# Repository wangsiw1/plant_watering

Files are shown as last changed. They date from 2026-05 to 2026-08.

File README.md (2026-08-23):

# Plant watering

A simple 1 main to multiple workers hardware setup to monitor soil moisture and water series of plant pots automatically.

Main device:
- Gateway of the setup, managing the workers, hosting web server for user interactions
- Monitoring water level from water container with capacitive sensor
- Controlling pump for watering

Worker device:
- Monitoring 1 or more soil moisture sensors and reporting to main
- Controlling 1 or more two-position three-way solenoid valves to redirect water to different plant pots

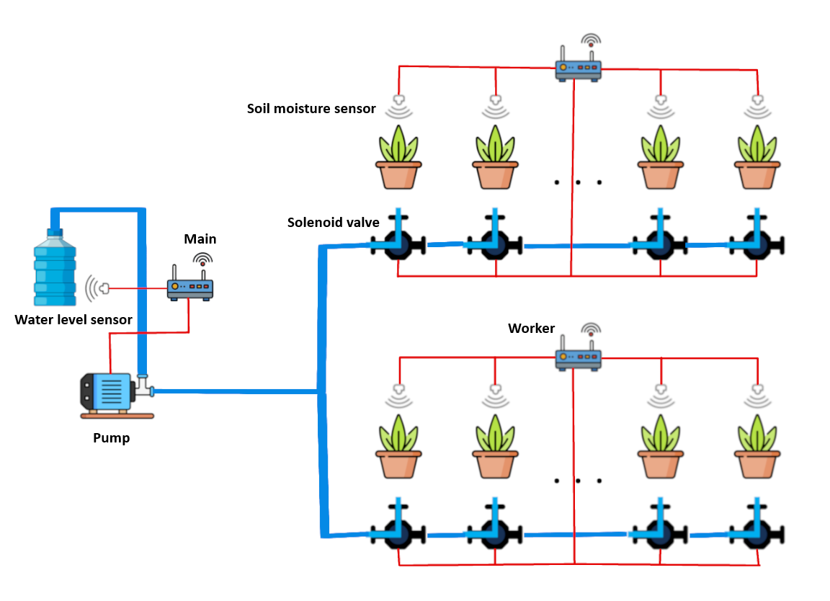
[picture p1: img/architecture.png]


> **Disclaimer**: LLM has been used in this project as part of the learning process. On hardware side, Google Gemini, Claude AI, and OpenAI ChatGPT were used to explain usage of components, knowledge cross check, and parts recommendation. On software side, GitHub Copilot agent in Visual Studio Code was used to generate part of the code based on design document. Human review, revise, and test was conducted every round of generation.

## Design

- MCU:
    Considering the price and wireless requirement, ESP32 C3 was chosen.

- Power: 
    - Since main device will do the heavy duties(Always on, WiFi connection and web server host, pump driving, etc.), a 12V DC input using common DC barrel plug adapter was used to provide continuous power. 
    - Amount of workers can be scaled up and locations varies based on the plant location, while worker can be less power hungry, rechargeable LiPo battery is used.

- Communication:
    - Bluetooth between main and worker for sensor reading reporting and watering command sending. 
    - For easy scalability and setup process, all devices use BLE broadcast to send messages and filter message by MAC address of sendor, no connection is required.

- Function:
    - Users add workers to main by Bluetooth MAC address. Main will probe added workers and learn details upon first status report(worker having 1/8/16 ports available)
    - Users set watering duration, soil moisture threshold, and automatic watering interval for each plant pot, plus the system-wide active time range and data-sync interval.
    - After enabling auto watering, main collects sensor readings, starts pump and commands workers to trigger solenoid valve, then let workers go to deep sleep mode during time interval to save power.
    - Solenoid valve will be triggered one by one, meaning only one pot will be watered at a single time, due to battery current and pump power limitation.

## Hardware

### V1

For the initial idea, because of the nature of similarity between main and worker(1 sensor, 1 peripheral), it was decided to use a single PCB design for both devices with compatibility added to fit different parts on the same board. 

Since a 12V pump was used, a 12V solenoid valve was also chosen. Then all differences are as follow:
- Different sockets for pump(screw terminal) and valve(GH 1.25 socket), lined up next to each other on the PCB, use one of them as needed.
- Different sensor pin numbers(3 pins for soil moisture and 4 pins for water level), since both are XH 2.54, and both have pin 3 as data output, put a single 4 pin footprint, and use different parts.
- Different VIN and GND pin sequences for sensors, use two 0 ohm with solder pads in 2*2 grid to bridge trace to achieve different sequences on different orientations.

Being first version of the project and first personal hardware project, this one has severe design flaws due to lacking of knowledge, hardware understanding, and product reasearch. It was scrapped later.

#### Shared Schematic & PCB

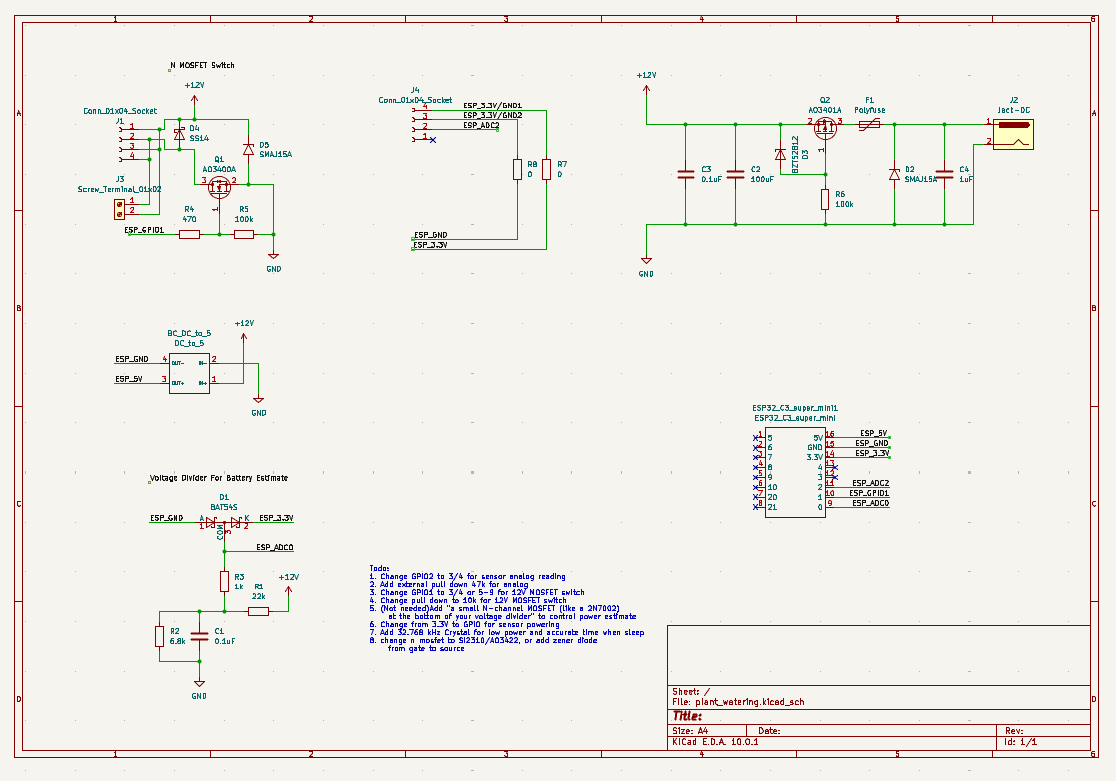
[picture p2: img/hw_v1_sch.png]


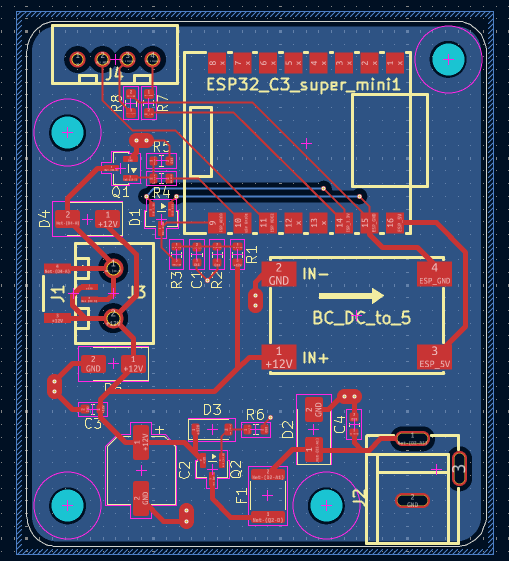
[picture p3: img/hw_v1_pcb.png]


#### Main

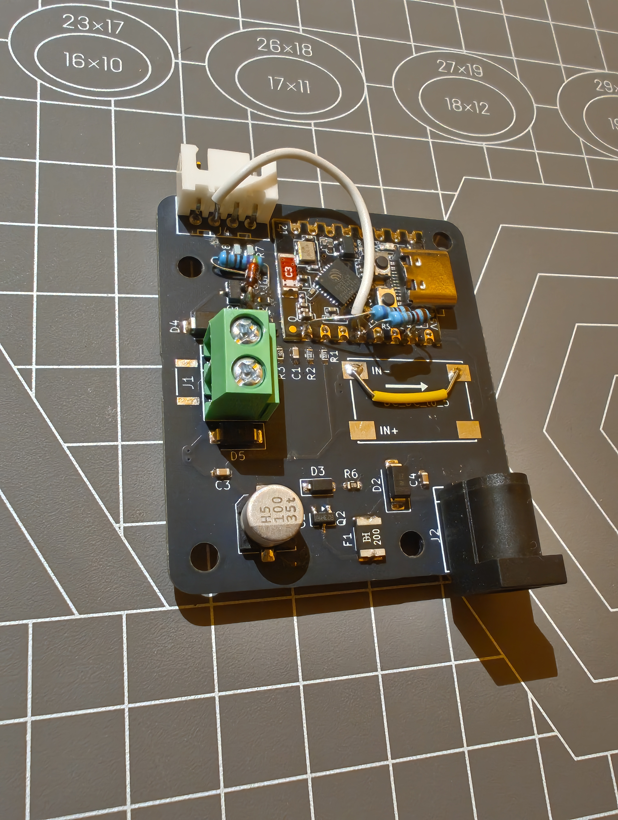
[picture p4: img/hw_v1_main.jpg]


#### Worker

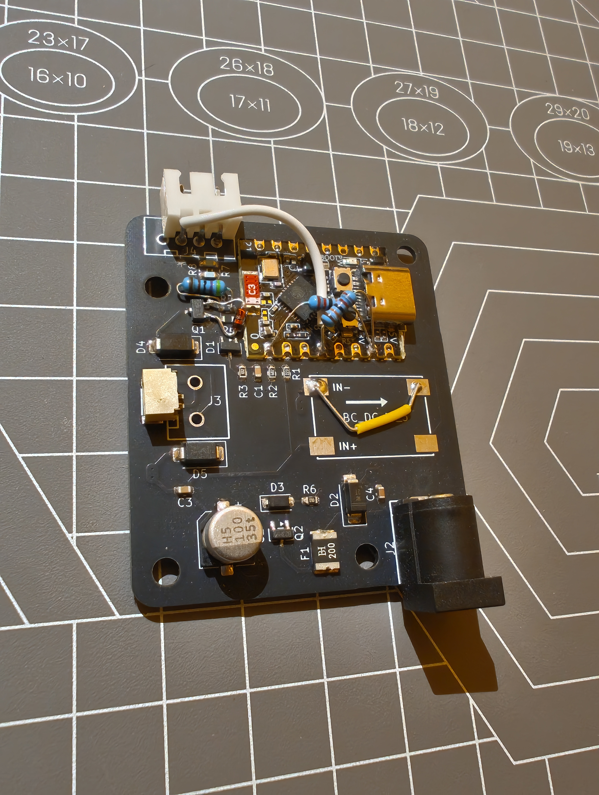
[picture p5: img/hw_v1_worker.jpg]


### V2

Design of main device is basically V1, but with dimension changed to fit case and worker compatibility removed, as worker is fully redesigned.

For worker, after reviewing the total cost of V1 worker, it was really expensive for users owning dozens of pots of plant. In V2, worker had numbers of monitored plant expand from 1 to 8, and can be expanded to 16 in the future.

To reduce cost and weight, power was cut from 12V to 5V. Battery was moved from large lithium battery pack to flat LiPo with charging & 5V boost converter module. Solenoid valve was also changed to a different 5V version.

There are still several minor issues with this version, not function breaking, but are documented in the schematic and shall be fixed in the next revision.

#### Main

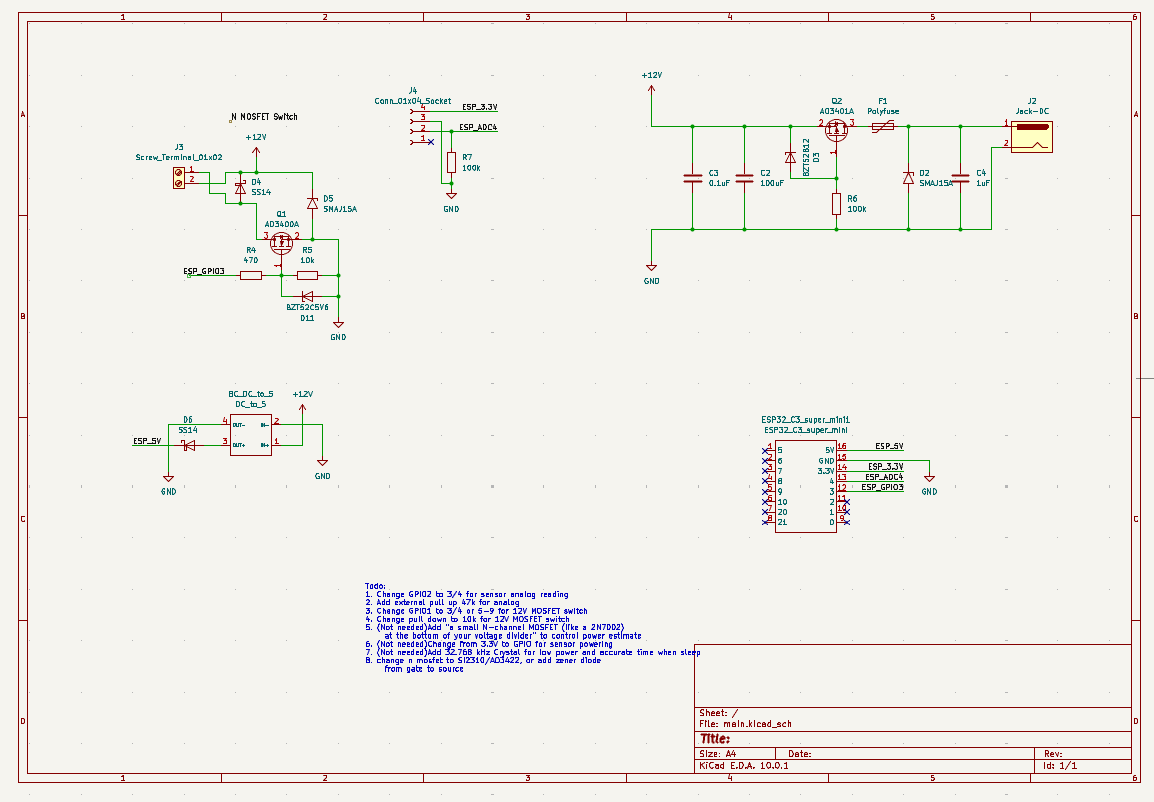
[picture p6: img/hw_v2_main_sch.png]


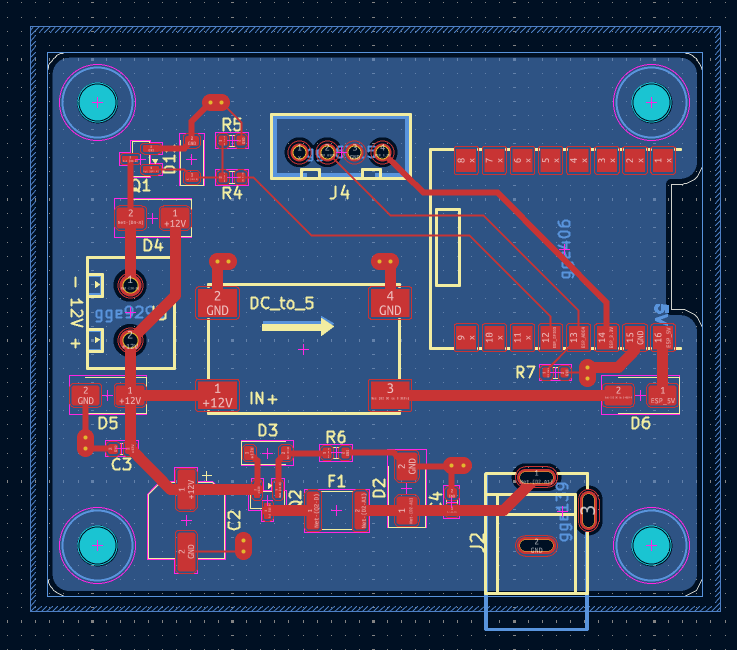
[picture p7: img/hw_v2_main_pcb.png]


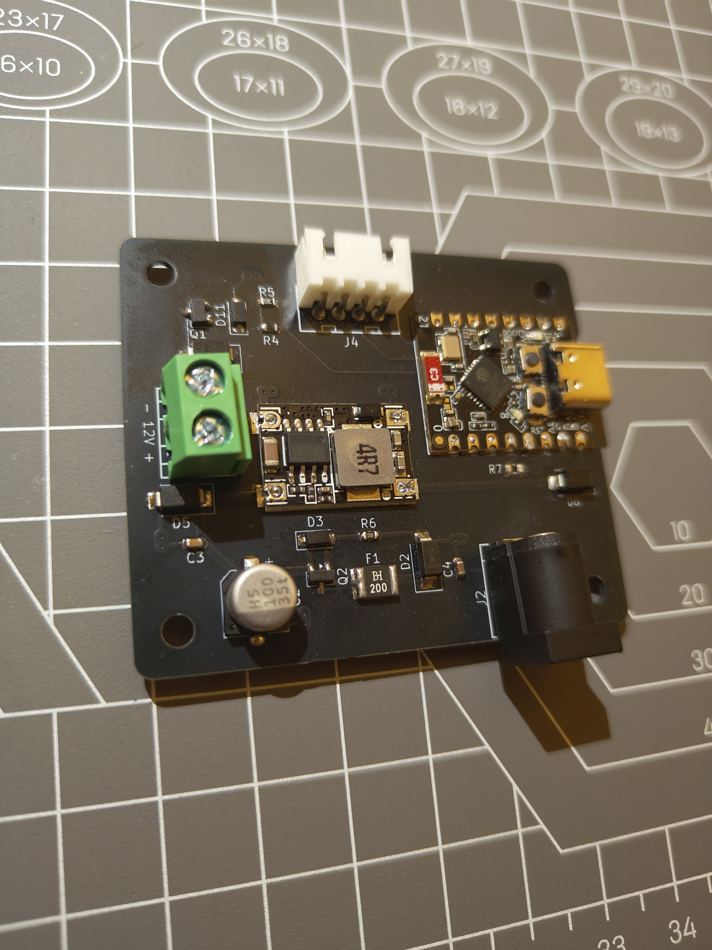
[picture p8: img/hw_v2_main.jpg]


#### Worker

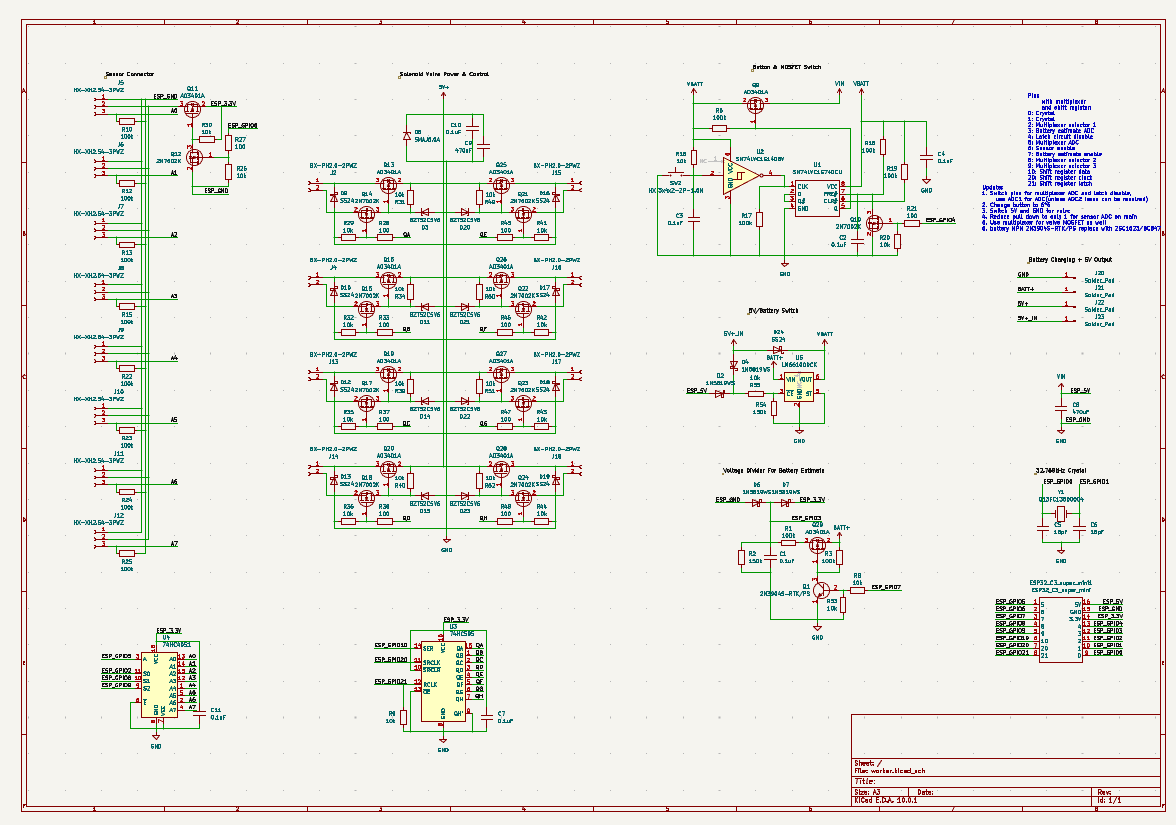
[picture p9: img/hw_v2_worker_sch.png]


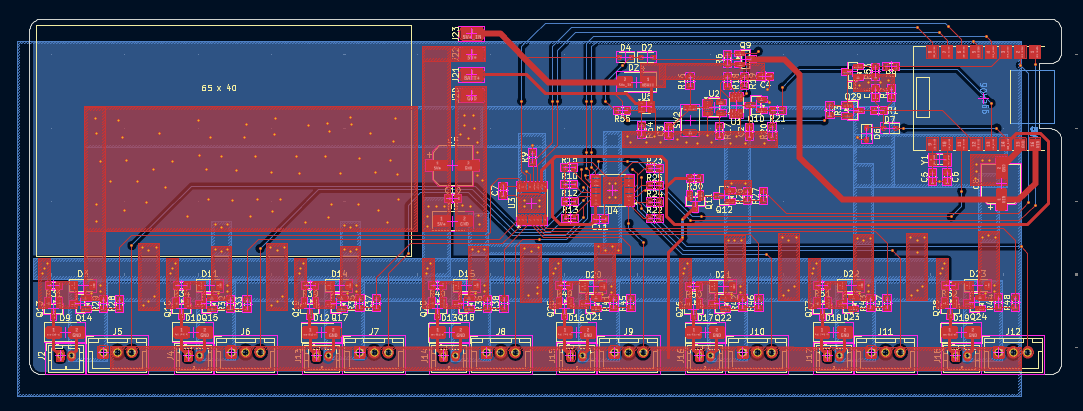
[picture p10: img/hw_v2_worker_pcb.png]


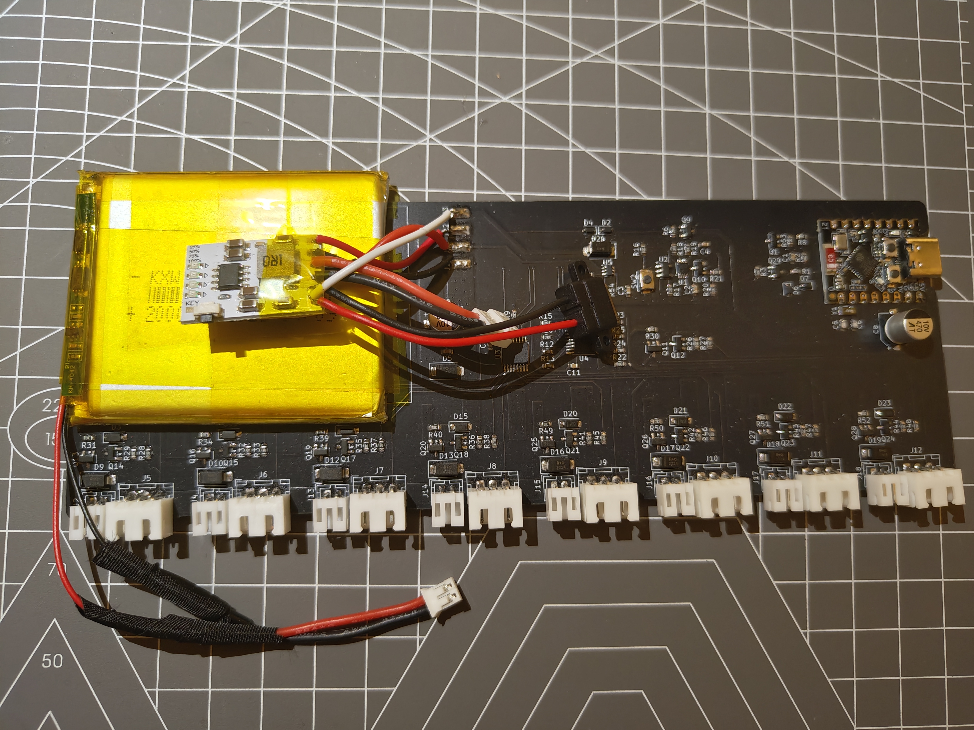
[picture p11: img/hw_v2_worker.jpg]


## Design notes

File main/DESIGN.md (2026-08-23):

# ESP32-C3 pot plan watering system — Design & Notes

This document collects requirements, design decisions, implementation notes of software for the main device of ESP32-C3 pot plant watering project.

Note: Hardware specifications other than ESP32 C3 is not in the scope.

## Overview

Goal: As a main device, it will have a non contact capacitive water level sensor and a water pump connnected. The device will collect soil sensor data from worker devices through Bluetooth broadcast, then based on the settings and sensor data, it will send commands to worker devices and start pump. This main device will also host an HTTP server that serves a web page for users to get info and config system. Detailed components are following:

- WiFi (WiFiProvisioner)
- mDNS
- OTA (ArduinoOTA, Async?)
- Wireless data reading and command sending (Bluetooth broadcast? No wifi channel issue, but range? packet loss?)
- HTTP server with a small web UI for worker device add/remove, settings, info, etc.
- Settings persistence across reboots
- Manual actions via the UI

## Functionalities

- Setup mDNS for easier web page access
- With WiFiProvisioner, let users connect to the on board WiFi first to select WiFi router to connect to. So that users can access web page directly through exsiting router without needing to change WiFi all the time.
- Bluetooth keeps listening the broadcast data and broadcasts commands when required. 
- ArduinoOTA for OTA. (Firmware image integrity check and rollback on fail need to be checked)
- Web page:
  - Show digital data from sensor
  - Last pump activation time
  - Set water pump activation time during the day
  - Cooldown after previous watering, no watering during this period, wait for water to go into soil
  - Manual pump activation
  - Enable/disable audo watering function based on schedule and soild moisture
  - Apply and save all inputs
  - Add worker node using Bluetooth MAC address
  - List of added worker nodes grouped by worker device, each worker shows:
    - Battery level, last sync time, and RSSI
    - Worker name input
    - For each pot on that worker: soil moisture, last watering time, threshold, watering duration, pot name, and manual watering button

### Details

- mDNS
  - Default settings
  - Domain name: plant-watering-\<WIFI_MAC_LAST_6_HEX\>.local
  - Initialize once and follow WiFi/IP events across reconnects; retry only if
    initial mDNS setup failed

- WiFiProvisioner
  - Default settings
  - On an eligible crash recovery with saved credentials, a connection timeout
    skips blocking provisioning so automation can boot offline and WiFi can
    reconnect in the background
  - All other failed startup connections retain the blocking provisioning flow

- ArduinoOTA
  - Main and worker OTA uploads and worker deployment require auto mode to be
    turned off first
  - Reject enabling auto mode while an OTA operation is active
  - Main and worker builds define a nonzero `FW_MIN_ALLOWED_VERSION` no greater
    than their own `FW_VERSION`
  - Reject packages below that role-specific minimum and reject reinstalling
    the currently running version; allow upgrades and rollbacks down to the floor

- Auto mode recovery
  - Keep the armed intent in validated RTC no-init memory, not NVS
  - Resume only after panic, interrupt-watchdog, task-watchdog, or other
    watchdog resets and only after normal startup initialization completes
  - Power-on, brownout, external, software/OTA, deep-sleep, SDIO, and unknown
    reset reasons always start in manual mode

- Web UI (Minimum style while easy to view)
  - Each input below has a tooltip explain the usage 
  - Title/header ("Plant Watering (\<name\>)", name is \<WIFI_MAC_LAST_6_HEX\> by default)
  - Name input (255 char max, empty by default. If non-empty, replace name in title)
  - Current time (hour:minute), and input to set manually
  - Water tank info from sensor: High/Low
  - Time range input of watering activation: 24-hour start and end
  - Interval of data sync input (seconds with hardcoded min/max)
  - Button to manually activate pump
  - Button to apply all changes
  - Major button to start auto watering
  - ID (12 hex digits of Bluetooth MAC address, upper or lower cases) input and add button to add worker node to list
  - Major button to apply changes to inputs
  - List of added worker nodes grouped by worker device:
    - Worker header shows MAC address, battery percentage, last sync time, and RSSI
    - Worker name input
    - Remove button removes the whole worker device from the list
    - Each pot row shows soil moisture data, persistent last automatic watering time, threshold, watering duration, watering interval, and a manual watering button
    - Pot name and worker name are stored in fixed 65-byte buffers, so the web UI clamps names to 64 UTF-8 bytes total, which is about 64 ASCII characters or about 16 4-byte emoji/CJK characters
  - Callapsed log list and system health info

- Hardware
  - Main firmware supports multiple hardware targets selected at build time
  - Main-device status LED
    - GPIO 8, active-low, onboard single-color blue LED
    - Driven by LEDC channel 0 at 5 kHz with 8-bit PWM resolution
    - The status controller updates every 20 ms in an independent low-priority
      FreeRTOS task, including while WiFi provisioning blocks the main setup
      flow
    - Display priority is logical and independent of FreeRTOS task priority:
      OTA update, low water tank, WiFi, watering, worker synchronization, then
      normal/idle
    - Main or worker OTA: 100 ms on and 100 ms off continuously (5 flashes per
      second)
    - Low tank (at or below 2800 mV): 500 ms on and 500 ms off continuously
      (1 flashes per second)
    - WiFi provisioning, initial connection, or reconnection: cosine-eased
      breathing over 2 seconds, from 10% PWM brightness at 0 ms to 70% at
      1000 ms and back to 10% at 2000 ms
    - WiFi connected: one 250 ms full-brightness confirmation flash, then off
      or the next applicable lower-priority state
    - Watering or manual pump active: three 100 ms flashes separated by 100 ms off,
      followed by 1500 ms off; repeat every 2 seconds
    - Worker synchronization: two 100 ms flashes separated by 100 ms off,
      followed by 1700 ms off; repeat every 2 seconds
    - Normal/idle: off
    - Pattern intervals are half-open and a newly selected highest-priority
      pattern restarts at its first phase
  - `HW_TARGET_V1_REV_A`
    - Pump activation pin: GPIO 1
    - Water tank level sensor reading pin: GPIO 3
  - `HW_TARGET_V2_REV_A`
    - Pump activation pin: GPIO 3
    - Water tank level sensor reading pin: GPIO 4

- Logics
  - Time
    - 24-Hour, minute level (HH:mm)
    - Input by user via web UI
    - Local-first operation: NTP is optional and manual HH:mm input must work on a network without Internet access
    - Keep a hidden epoch day so multi-day watering intervals can be measured while only HH:mm is exposed to the user
    - Restore the later sane value from retained system time or the saved checkpoint; otherwise start at 2000-01-01 00:00 UTC as a usable default clock
    - Advance time from the 64-bit monotonic ESP timer and accept that elapsed time while fully powered off may be lost
    - Checkpoint approximate time every six hours and before an intentional main-controller OTA reboot
    - NTP synchronization is asynchronous and attempted at startup, after WiFi reconnect, after reset while connected, or by explicit user request; failure never invalidates the current clock
    - Preserve elapsed time since each pot's last automatic watering when manual or NTP correction changes the hidden epoch
    - Use this current time for watering time range when auto watering is enabled
  - Wifi
    - If WiFiProvisioner could not connect to any Wifi, setup on board Wifi, allow users connecting to ESP32 C3's AP and access HTTP server through default IP/mDNS
  - Watering
    - With major button switching between manual and auto, manual by default
    - Always follow water tank level sensor reading to force stop watering
    - Manual mode
      - Enable pump activation button to trigger pump
      - Enable valve activation button to send Bluetooth broadcast message to certain node to trigger valve
    - Auto mode
      - Disable pump activation button
      - Disable valve activation button
      - Only activate if water tank level is not low
      - Only activate during active time range
      - Only activate a pot after that pot's watering interval
      - Only activate a pot if its reported soil moisture is above its threshold
      - Soil sensor ADC value increases as the soil gets drier
  - Watering interval
    - Per-pot cooldown timer that prevents that pot from automatic watering
    - Starts from the end of the last successful automatic watering batch containing that pot
    - Manual watering does not reset the automatic cooldown
    - Pots are evaluated only on data sync cycles, so the effective interval is also limited by the data sync interval
    - Minimum: 60 seconds
    - Maximum: 2,419,200 seconds (28 days)
    - Default: 3600 seconds (1 hour)
  - Data sync interval
    - Cooldown timer until next data change between main and worker nodes
    - In auto mode, after each sync/watering cycle main sends the next sleep delay and workers go to deep sleep for this interval
    - In manual mode, main does not send sleep commands, so paired workers stay awake waiting for commands and unpaired workers keep advertising periodically
    - Minimum: 60 seconds
    - Maximum: 2,419,200 seconds (28 days)
    - Default: 3600 seconds (1 hour)
  - Data sync
    - TLV format
    - Main to worker
      - Bluetooth MAC address of target worker
      - Duration until next data sync
    - Worker to main
      - Bluetooth MAC address of main node
      - Soil moisture
      - Battery level
  - Bluetooth
    - Broadcast with ACKs
    - Extended advertising is required
  - Workflow
    - Main node
      - Always on
      - Host HTTP server
      - Monitor water tank level sensor
      - Only accepts status updates from worker MAC addresses that have already been added in the web UI
      - Maintain time
      - In manual mode, probe configured workers about every 30 seconds and do not send sleep commands afterward
      - In auto mode, probe workers on the configured data sync interval, evaluate watering, then send sleep commands for the next cycle
    - Worker node
      - When not paired with a main node, advertise status periodically with target node Bluetooth MAC FF:FF:FF:FF:FF:FF
      - When paired and main auto mode is off, stay awake waiting for commands from main
      - When paired and main sends a sleep command, go to deep sleep until the requested timer expires, then wake and wait for the next probe
      - Monitor soil moisture sensor
    - Worker node connection procedure
      - Not exactly connection, but as long as main node is able to communicate with a configured worker, mark it as connected
      - Worker node starts broadcasting data periodically after power up
      - Main node ignores worker status messages until that worker MAC address is added to the list
      - The first accepted command teaches the worker the main node MAC address
      - If Bluetooth MAC address of worker node is added to list in main node, main node should proceed to standard device timing coordination
    - Device timing coordination procedure
      - This procedure only runs in auto mode
      - Main node calculates next data sync time
      - With calculated delay time for each worker node, all worker should wake up around similar time
      - After watering procedure done, main node should calculate new time and send to workers, then workers go to sleep
        1. Main node broadcasts sleep time to the worker one by one
        2. Worker broadcasts ACK
        3. Worker go to sleep
    - Data sync procedure
      - In auto mode, after data sync interval plus extra small delay, assuming all worker nodes wake up, for each worker in the worker list:
        1. Main node broadcasts probe to the worker
        2. Worker listens and broadcasts data
        3. Main node broadcasts ACK
      - In manual mode, main still probes configured workers periodically, but skips the later sleep-coordination step
    - Watering procedure
      - After data sync, if all conditions meet the watering requirement
        1. For each worker with dry pots, main starts its water-command advertisement
        2. Main starts the pump as soon as that advertisement has started
        3. Worker completes its ACK advertisement and activates valves sequentially
        4. Worker stops the valves and sends `TYPE_EVENT_WATER_DONE`
        5. Main ACKs completion, stops the pump, and continues coordination
      - If conditions not meet, skip to device timing coordination procedure
    - Worker node retry and disconnect procudure
      - Either main node or worker node is not responding to message after certain time lenght, retry 3 times
      - If worker node does not respond after retries, main node marks it as disconnected and continue
      - If main node does not respond to worker node, reset the worker node itself and start over from worker node connection procedure

## Logging

With only very limited on-board memory and storage on ESP32 C3, long-time info level logging is challenging. For now only log warning level with date, time and minimum info:

- Sensor data history
  - Find water tank level is low
  - ...
- System health log
  - Find worker node disconnected
  - ...

## Security & privacy notes

The system is designed to run within a home LAN, not exposed to internet directly, and not using private information. The level of security requirement is considered low, but following points can be considered to be implemented:

- Web UI authentication (password, use "watering" as default for now, there is no physic button to reset in case password is changed and forgotten)
- Secured OTA update (ArduinoOTA supports username and password, use "admin" and "watering" for same reason)
- Bluetooth data encryption (unlikely unless easy to do)

## Edge cases & limitations

- There is no pump health info(not connected, broken, etc.)
- Very limited on-board memory and storage

## Next improvements (suggested tasks)

TBD

## Bluetooth Protocol

The main and worker firmware must be deployed as a matched pair. The protocol requires
BLE extended advertising; there is no legacy-advertising or plaintext fallback.

### Envelope

- Company identifier: 2 bytes, `0xFFFF` for this project.
- Target MAC: 6 bytes, or `FF:FF:FF:FF:FF:FF` for an unpaired status broadcast.
- Session ID: 8-byte big-endian random value generated at every boot.
- Sequence: 4-byte big-endian counter, nonzero and unique within the boot session.
- Encrypted body: AES-GCM ciphertext followed by a 16-byte authentication tag.

The authenticated body starts with one message-type byte. Remaining values use TLV
fields encoded as `[field type:1][length:1][value:length]`; integers are big-endian.

### Messages

- `0x20 TYPE_ACK`: no TLV fields. It repeats the acknowledged session and sequence.
- `0x30 TYPE_CMD_PROBE`: no TLV fields.
- `0x31 TYPE_CMD_SLEEP`: `FIELD_SLEEP_SEC` as one `uint32`.
- `0x32 TYPE_CMD_WATER`: `FIELD_POT_MASK` plus `FIELD_DURATION_LIST`.
- `0x40 TYPE_STATUS`: battery, pot count, the ordered `uint16` soil list, and
  optional `FIELD_FW_VERSION` (`0x07`) as one `uint32`. Main treats a missing
  version from legacy workers as unknown and keeps it only in runtime memory.
- `0x41 TYPE_CONFIG`: reserved placeholder; it is not currently transmitted.
- `0x42 TYPE_EVENT_WATER_DONE`: the completed pot mask.

ACK matching uses source MAC, session ID, and sequence. For an unpaired broadcast status,
the first authenticated ACK with the matching message ID completes the transaction but
does not pair the worker.

### Encryption

AES-GCM uses the target MAC, session ID, and sequence as authenticated header data.
The 12-byte IV is the first 12 bytes of:

`HMAC-SHA256(network_key, target_mac || session_id || sequence || "btiv")`

Decryption failure rejects the packet. The current compiled network key is a development
placeholder and must be provisioned securely for a production deployment.

### Runtime Flow

- One sender task owns the advertising instance for the complete advertisement lifetime.
  ACK jobs are inserted at the front of its bounded queue.
- Main probes one configured worker at a time, requires the probe ACK, and then waits for
  a newer status generation before using that worker's readings.
- Main ignores and does not ACK status from workers absent from its configured list.
- Worker learns a main MAC only from a valid supported command, never from an ACK.
- Worker scan callbacks only validate and queue commands. A control task sends the ACK,
  waits for its advertisement to finish, and then performs watering or deep sleep.
- For automatic watering, the pump starts when the water-command advertisement actually
  starts. A missing command ACK does not stop the pump; completion, timeout, or low tank
  level ends the watering window.
- Sleep commands are transactional. A worker enters deep sleep only after its ACK
  advertisement has completed.

## Intentional Placeholders

- `TYPE_CONFIG`, heap monitoring, and the incomplete 16-pot hardware target remain.
- Main and worker retain separate copies of Bluetooth common and crypto sources so each
  firmware directory remains independently manageable.

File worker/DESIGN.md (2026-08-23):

# ESP32-C3 pot plan watering system — Design & Notes

This document collects requirements, design decisions, implementation notes of software for the worker device of ESP32-C3 pot plant watering project.

Note: Hardware specifications other than ESP32 C3 is not in the scope.

## Overview

Goal: As a worker device, it will have a capacitive soil moisture sensor and a solenoid valve connected. The device will read soil sensor data and send to main device via Bluetooth broadcasting, active or deactive pump, or go to sleep following the command from main devic. 

### Details

- Hardware
  - Worker firmware supports multiple hardware targets selected at build time
  - `HW_V1_1POT_REV_A`
    - Pot count: 1
    - Valve activation pin: GPIO 1
    - Battery pin: GPIO 4
    - Soil moisture sensor reading pin: GPIO 3
  - `HW_V2_8POT_REV_A`
    - Pot count: 8
    - Multiplexed soil sensing, shift-register valve control, and separate battery enable/ADC pins
    - Requires the external 32.768 kHz RTC crystal
  - `HW_V2_8POT_REV_B`
    - Pot count: 8
    - Same general architecture as rev A with alternate pin assignments
    - Requires the external 32.768 kHz RTC crystal
  - `HW_TARGET_16POT_REV_A`
    - Pot count: 16
    - Multiplexed soil sensing with shift-register valve control

- Logics
  - Data sync interval
    - Cooldown timer until next data change between main and worker nodes
    - In auto mode, the worker enters deep sleep only after main sends a sleep command with the next delay
    - In manual mode, the worker does not sleep for this interval and instead stays awake if paired
    - Minimum: 60 seconds
    - Maximum: 2,419,200 seconds (28 days)
    - Default: 3600 seconds (1 hour)
  - Data sync
    - TLV format
    - Main to worker
      - Bluetooth MAC address of target worker
      - Duration until next data sync
    - Worker to main
      - Bluetooth MAC address of main node
      - Soil moisture
      - Battery level
      - Firmware version
  - Bluetooth
    - Broadcast with ACKs
    - Extended advertising is required
  - Workflow
    - Worker node
      - When not paired with a main node, advertise status periodically with target node Bluetooth MAC FF:FF:FF:FF:FF:FF
      - When paired and the main node is running manual mode, stay awake waiting for commands from that main node
      - When paired and the main node sends a sleep command, go to deep sleep, wake after the requested timer, and wait for the next probe
      - Monitor soil moisture sensor
    - Worker node connection procedure
      - Not exactly connection, but as long as main node is able to communicate with worker, mark it as connected
      - Worker node starts broadcasting data periodically after power up
      - Main node only proceeds after that worker MAC address is explicitly added to the configured list
      - The first accepted command teaches the worker which main-node MAC address to trust afterward
    - Device timing coordination procedure
      - This procedure only applies while the main node is in auto mode
      - Main node calculates next data sync time
      - With calculated delay time for each worker node, all worker should wake up around similar time
      - After watering procedure done, main node should calculate new time and send to workers, then workers go to sleep
        1. Main node broadcasts sleep time to the worker one by one
        2. Worker broadcasts ACK
        3. Worker go to sleep
    - Data sync procedure
      - In auto mode, after data sync interval plus extra small delay, assuming all worker nodes wake up, for each worker in the worker list:
        1. Main node broadcasts probe to the worker
        2. Worker listens and broadcasts data
        3. Main node broadcasts ACK
      - In manual mode, the worker still responds to periodic probes from main, but does not expect a follow-up sleep command
    - Watering procedure
      - After data sync, if all conditions meet the watering requirement
        1. Main starts the water-command advertisement and then starts the pump
        2. Worker completes its ACK advertisement before operating any valve
        3. Worker waters selected pots sequentially and sends `TYPE_EVENT_WATER_DONE`
        4. Main ACKs completion and stops the pump
      - If conditions not meet, skip to device timing coordination procedure
    - Worker node retry and disconnect procudure
      - Either main node or worker node is not responding to message after certain time lenght, retry 3 times
      - If worker node does not respond after retries, main node marks it as disconnected and continue
      - If main node does not respond to worker node, reset the worker node itself and start over from worker node connection procedure

## Bluetooth Protocol

Main and worker firmware are a matched protocol pair. Extended advertising and AES-GCM
are mandatory; packets that cannot be authenticated are discarded.

The manufacturer-data envelope is:

- Company identifier: 2 bytes (`0xFFFF`).
- Target MAC: 6 bytes.
- Random boot session ID: 8 bytes, big-endian.
- Per-session sequence: 4 bytes, big-endian.
- AES-GCM encrypted body and 16-byte authentication tag.

The body begins with a message type followed by TLVs encoded as
`[field type][length][value]`. ACKs repeat the message ID in the envelope and are matched
with the advertiser MAC.

The IV is the first 12 bytes of:

`HMAC-SHA256(network_key, target_mac || session_id || sequence || "btiv")`

The target MAC, session ID, and sequence are also authenticated as GCM associated data.

Worker behavior:

- An unpaired status targets the broadcast MAC. Its ACK completes transmission without
  teaching the worker a main MAC.
- Only a valid probe, water, or sleep command can establish the retained main MAC.
- Scan callbacks authenticate and queue commands without operating hardware.
- The worker-control task completes the command ACK advertisement before acting.
- Water commands operate valves sequentially and finish with `TYPE_EVENT_WATER_DONE`.
- Sleep begins only after the sleep-command ACK advertisement is complete.
- One periodic task samples battery first and soil second every five seconds, publishing
  both through one protected sensor snapshot.
- Status includes `FIELD_FW_VERSION` (`0x07`) as a big-endian `uint32`.

Worker OTA accepts upgrades and rollbacks at or above the build-defined
`FW_MIN_ALLOWED_VERSION`. It rejects the currently installed version and any package
below that floor before firmware image transfer begins.

`TYPE_CONFIG` remains reserved and unused. Bluetooth common and crypto files intentionally
remain duplicated between the two independently managed firmware directories.

## Hardware Build Variants

This worker firmware supports multiple hardware variants selected at compile time via a
single `HW_*` build flag. The flag determines pin mappings and the number of pots.

Examples:
- `HW_V1_1POT_REV_A` : original single-pot hardware (SOIL_PIN=3, VALVE_PIN=1)
- `HW_V2_8POT_REV_A` : 8-pot with multiplexer (3 select pins) + one shift-register chip
- `HW_V2_8POT_REV_B` : 8-pot variant with alternate pin assignments

The 16-pot target remains an intentional placeholder with incomplete pin mapping.

## V2 RTC Clock Boot Gate

Both V2 8-pot workers require the external 32.768 kHz crystal as the RTC slow
clock. ESP-IDF requests that source with 3000 calibration cycles. The application
then checks the source selected by ESP-IDF at the beginning of `app_main()`, before
NVS, Arduino, sensors, valves, Bluetooth, or OTA are initialized.

- `SOC_RTC_SLOW_CLK_SRC_XTAL32K` passes the gate and normal startup continues.
- Any internal or invalid source fails the gate. GPIO8 is configured as the
  active-low onboard blue LED (low is on; high is off) and displays the RTC
  fault pattern below.
- A successful check produces no flash. The LED is explicitly turned off before
  startup continues, and `sensorBegin()` later takes ownership of GPIO8 as
  `MUX_SEL_PIN1`. No LED controller writes GPIO8 during normal operation; visible
  activity caused by multiplexer selection is incidental.

The RTC failure indication uses half-open intervals and is evaluated every 10 ms:

| Cycle interval | LED state |
|---|---|
| 0-100 ms | On |
| 100-200 ms | Off |
| 200-300 ms | On |
| 300-400 ms | Off |
| 400-500 ms | On |
| 500-2000 ms | Off |

This two-second cycle repeats 30 times, for exactly 60 seconds of fault
indication. The LED is then turned off and the worker enters timer-only deep sleep
for five seconds. Deep-sleep wake runs ESP-IDF clock initialization again, which
re-enables and calibrates the external crystal. A recovered crystal permits normal
startup; a continuing failure starts another indication and recovery cycle. The
fallback clock may make the five-second recovery interval imprecise, which is
acceptable for this retry.

Deep-sleep recovery retains the worker's `RTC_DATA_ATTR` main-device MAC and last
command ID. The XTAL32K watchdog is configured with a timeout value of 200 and
automatic backup-clock switching, so a crystal failure during deep sleep switches
RTC timing to the RC-derived backup and allows the timer wakeup to continue. No
runtime callback or fault task is installed: if the worker is awake when a failure
occurs, it may continue temporarily on the backup clock until its next deep-sleep
wake or reset.

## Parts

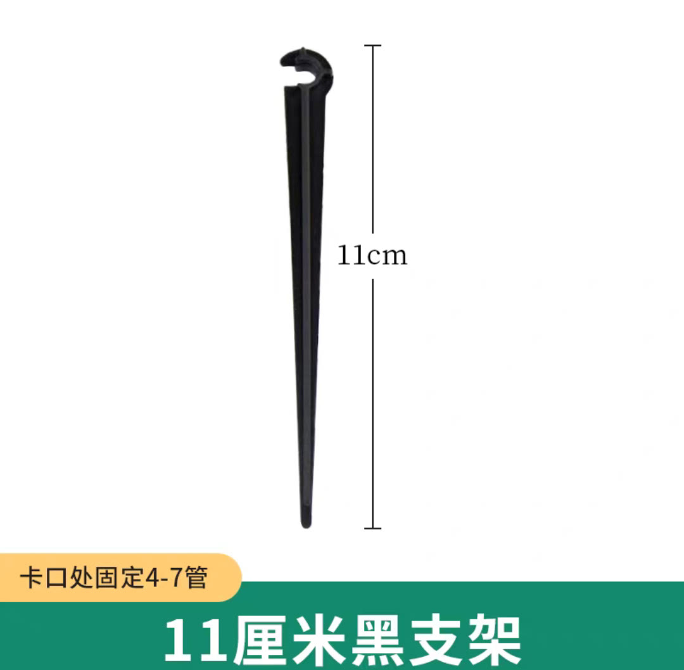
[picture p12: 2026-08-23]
manual/assets/optimized/parts/pipe_holder_4_7.jpg

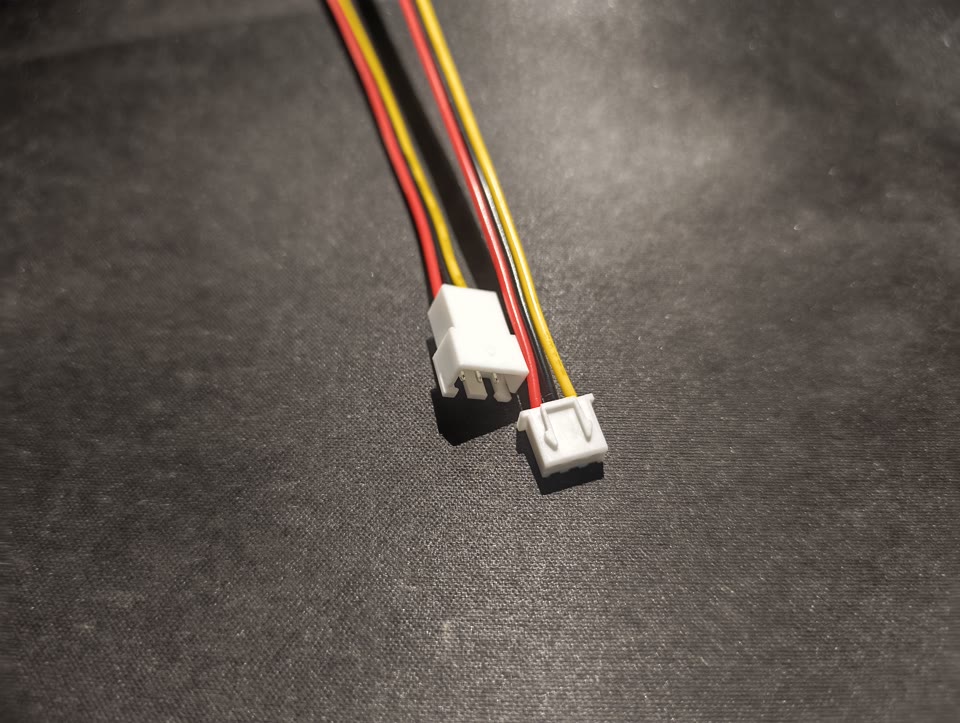
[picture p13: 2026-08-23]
manual/assets/optimized/parts/xh254_3pins_m_to_f.jpg

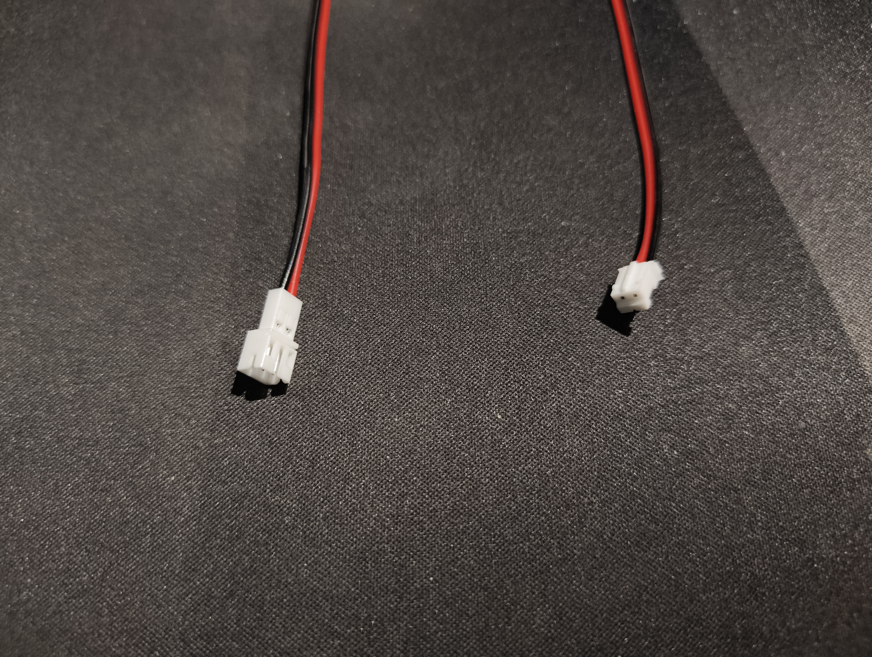
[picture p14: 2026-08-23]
manual/assets/parts/ph20_2pins_m_to_f.jpg

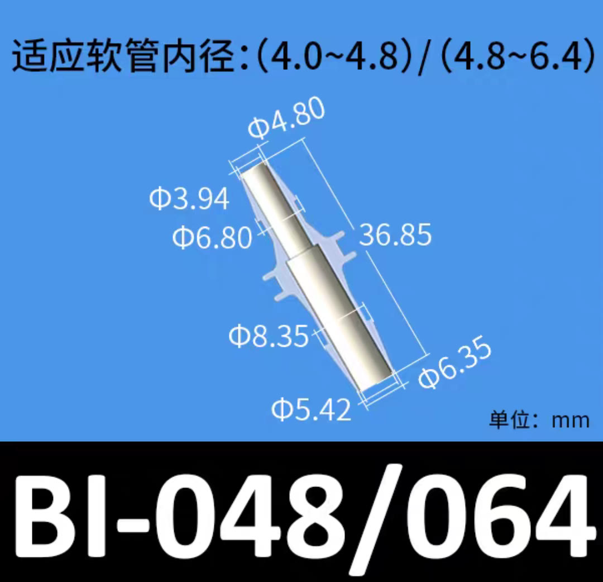
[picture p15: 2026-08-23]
manual/assets/optimized/parts/pipe_adapter_048_064.jpg

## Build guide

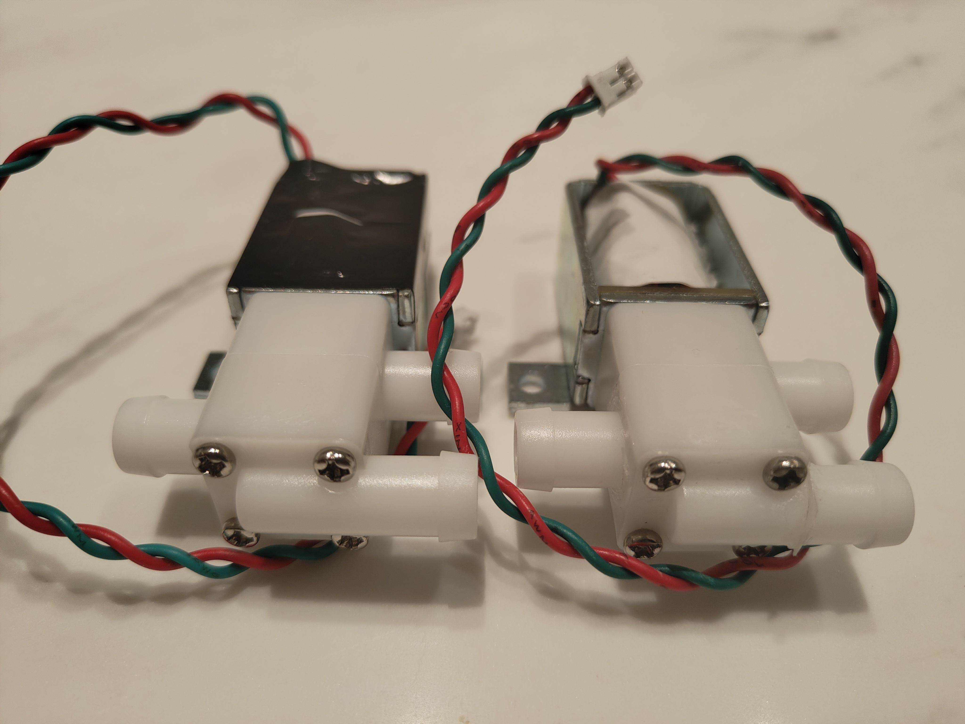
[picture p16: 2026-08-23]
manual/assets/valve_insulate_tape.jpg

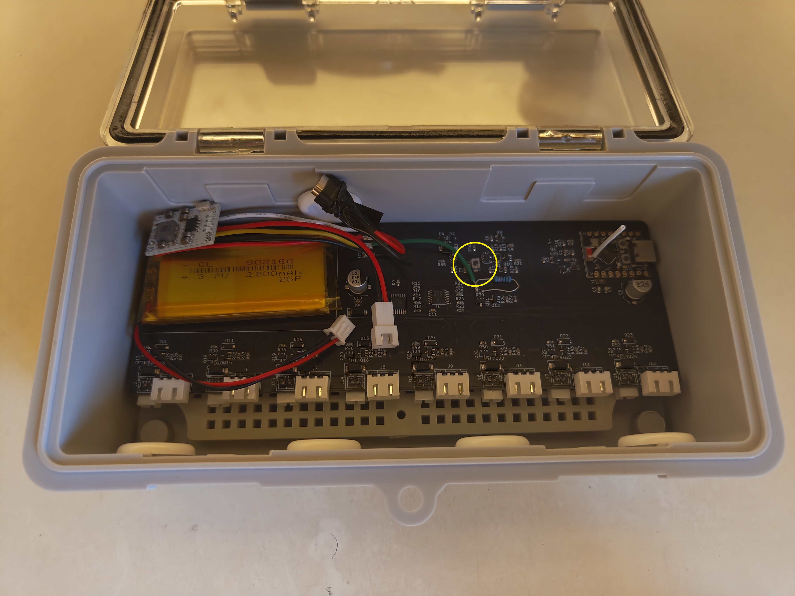
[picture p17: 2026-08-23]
manual/assets/worker_device_v2.jpg

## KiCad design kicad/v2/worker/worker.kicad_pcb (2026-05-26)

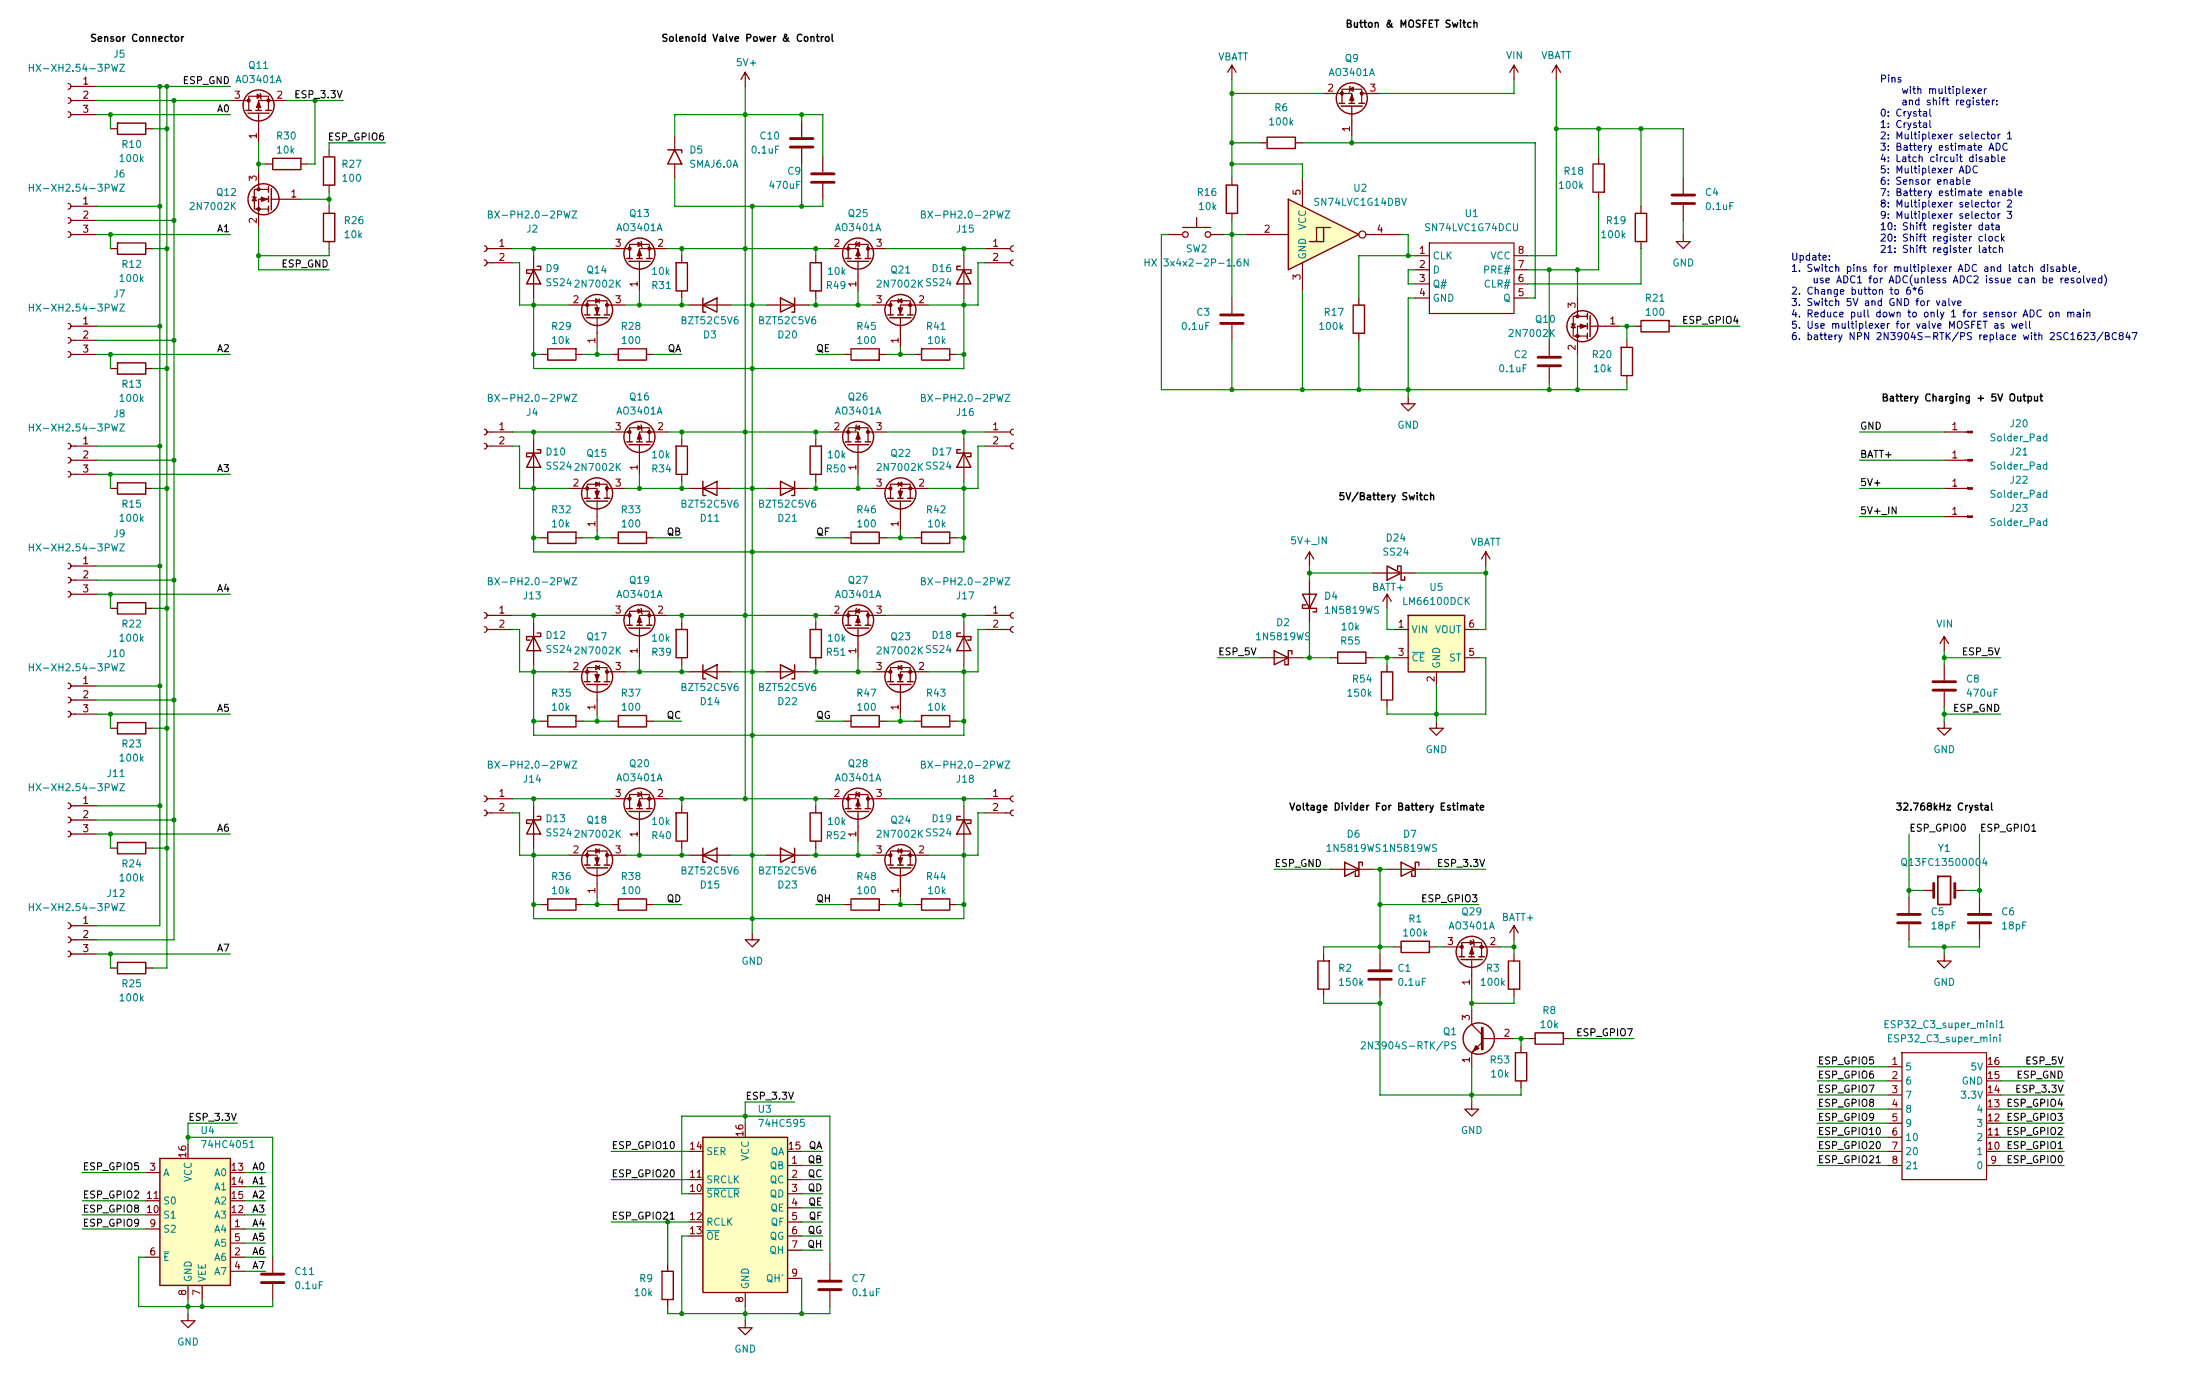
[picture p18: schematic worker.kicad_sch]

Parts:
C1, C2, C3, C4, C7, C10, C11: 0.1uF; C_0603_1608Metric
C5, C6: 18pF; C_0603_1608Metric
C8, C9: 470uF; CP_Elec_6.3x7.7
D2, D4, D6, D7: 1N5819WS; D_SOD-323
D3, D11, D14, D15, D20, D21, D22, D23: BZT52C5V6; D_SOD-123
D5: SMAJ6.0A; D_SMA
D9, D10, D12, D13, D16, D17, D18, D19, D24: SS24; D_SMA
ESP32_C3_super_mini1: ESP32_C3_super_mini; 1_ESP32_C3_super_mini-SMD_16P-L22.5-W18.0-P2.54-TL
J2, J4, J13, J14, J15, J16, J17, J18: BX-PH2.0-2PWZ; JST_PH_B2B-PH-K_1x02_P2.00mm_Vertical
J5, J6, J7, J8, J9, J10, J11, J12: HX-XH2.54-3PWZ; JST_XH_B3B-XH-A_1x03_P2.50mm_Vertical
J20, J21, J22, J23: Solder_Pad; SolderWirePad_1x01_SMD_2x4mm
Q1: 2N3904S-RTK/PS; SOT-23
Q9, Q11, Q13, Q16, Q19, Q20, Q25, Q26, Q27, Q28, Q29: AO3401A; SOT-23
Q10, Q12, Q14, Q15, Q17, Q18, Q21, Q22, Q23, Q24: 2N7002K; SOT-23
R1, R3, R6, R10, R12, R13, R15, R17, R18, R19, R22, R23, R24, R25: 100k; R_0603_1608Metric
R2, R54: 150k; R_0603_1608Metric
R8, R9, R16, R20, R26, R29, R30, R31, R32, R34, R35, R36, R39, R40, R41, R42, R43, R44, R49, R50, R51, R52, R53, R55: 10k; R_0603_1608Metric
R21, R27, R28, R33, R37, R38, R45, R46, R47, R48: 100; R_0603_1608Metric
SW2: HX 3x4x2-2P-1.6N; SW_Push_SPST_NO_Alps_SKRK
U1: SN74LVC1G74DCU; VSSOP-8_2.3x2mm_P0.5mm
U2: SN74LVC1G14DBV; SOT-23-5
U3: 74HC595; TSSOP-16_4.4x5mm_P0.65mm
U4: 74HC4051; TSSOP-16_4.4x5mm_P0.65mm
U5: LM66100DCK; SOT-363_SC-70-6
Y1: Q13FC13500004; Crystal_SMD_3215-2Pin_3.2x1.5mm

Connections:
5V+: C9.1, C10.2, D5.1 (A1), J22.1 (Pin_1_1), Q13.2 (S), Q16.2 (S), Q19.2 (S), Q20.2 (S), Q25.2 (S), Q26.2 (S), Q27.2 (S), Q28.2 (S), R31.2, R34.2, R39.2, R40.2, R49.2, R50.2, R51.2, R52.2
5V+_IN: D4.2 (A), D24.2 (A), J23.1 (Pin_1_1)
/A0: J5.3, R10.2, U4.13 (A0)
/A1: J6.3, R12.2, U4.14 (A1)
/A2: J7.3, R13.2, U4.15 (A2)
/A3: J8.3, R15.2, U4.12 (A3)
/A4: J9.3, R22.2, U4.1 (A4)
/A5: J10.3, R23.2, U4.5 (A5)
/A6: J11.3, R24.2, U4.2 (A6)
/A7: J12.3, R25.2, U4.4 (A7)
/ESP_3.3V: C7.2, C11.2, D7.1 (K), ESP32_C3_super_mini1.14 (3.3V), Q11.2 (S), R30.2, U3.10 (~SRCLR), U3.16 (VCC), U4.16 (VCC)
/ESP_GPIO0: C5.1, ESP32_C3_super_mini1.9 (0), Y1.1
/ESP_GPIO1: C6.1, ESP32_C3_super_mini1.10 (1), Y1.2
/ESP_GPIO2: ESP32_C3_super_mini1.11 (2), U4.11 (S0)
/ESP_GPIO3: C1.2, D6.1 (K), D7.2 (A), ESP32_C3_super_mini1.12 (3), R1.1, R2.2
/ESP_GPIO4: ESP32_C3_super_mini1.13 (4), R21.2
/ESP_GPIO5: ESP32_C3_super_mini1.1 (5), U4.3 (A)
/ESP_GPIO6: ESP32_C3_super_mini1.2 (6), R27.1
/ESP_GPIO7: ESP32_C3_super_mini1.3 (7), R8.2
/ESP_GPIO8: ESP32_C3_super_mini1.4 (8), U4.10 (S1)
/ESP_GPIO9: ESP32_C3_super_mini1.5 (9), U4.9 (S2)
/ESP_GPIO10: ESP32_C3_super_mini1.6 (10), U3.14 (SER)
/ESP_GPIO20: ESP32_C3_super_mini1.7 (20), U3.11 (SRCLK)
/ESP_GPIO21: ESP32_C3_super_mini1.8 (21), R9.2, U3.12 (RCLK)
/QA: R28.1, U3.15 (QA)
/QB: R33.1, U3.1 (QB)
/QC: R37.1, U3.2 (QC)
/QD: R38.1, U3.3 (QD)
/QE: R45.1, U3.4 (QE)
/QF: R46.1, U3.5 (QF)
/QG: R47.1, U3.6 (QG)
/QH: R48.1, U3.7 (QH)
BATT+: J21.1 (Pin_1_1), Q29.2 (S), R3.1, U5.1 (VIN)
GND: C1.1, C2.1, C3.1, C4.1, C5.2, C6.2, C7.1, C8.2, C9.2, C10.1, C11.1, D3.2 (A), D5.2 (A2), D6.2 (A), D9.2 (A), D10.2 (A), D11.2 (A), D12.2 (A), D13.2 (A), D14.2 (A), D15.2 (A), D16.2 (A), D17.2 (A), D18.2 (A), D19.2 (A), D20.2 (A), D21.2 (A), D22.2 (A), D23.2 (A), ESP32_C3_super_mini1.15 (GND), J2.2, J4.2, J5.1, J6.1, J7.1, J8.1, J9.1, J10.1, J11.1, J12.1, J13.2, J14.2, J15.2, J16.2, J17.2, J18.2, J20.1 (Pin_1_1), Q1.1 (E), Q10.2 (S), Q12.2 (S), Q14.2 (S), Q15.2 (S), Q17.2 (S), Q18.2 (S), Q21.2 (S), Q22.2 (S), Q23.2 (S), Q24.2 (S), R2.1, R9.1, R10.1, R12.1, R13.1, R15.1, R17.2, R20.1, R22.1, R23.1, R24.1, R25.1, R26.1, R29.1, R32.1, R35.1, R36.1, R41.1, R42.1, R43.1, R44.1, R53.1, R54.1, SW2.1, U1.4 (GND), U2.3 (GND), U3.8 (GND), U3.9 (QH'), U3.13 (~OE), U4.6 (~E), U4.7 (VEE), U4.8 (GND), U5.2 (GND), U5.5 (ST)
unnamed: C3.2, R16.1, SW2.2, U2.2
unnamed: D2.1 (K), D4.1 (K), R55.2
unnamed: D3.1 (K), Q13.1 (G), Q14.3 (D), R31.1
unnamed: D9.1 (K), J2.1, Q13.3 (D)
unnamed: D10.1 (K), J4.1, Q16.3 (D)
unnamed: D11.1 (K), Q15.3 (D), Q16.1 (G), R34.1
unnamed: D12.1 (K), J13.1, Q19.3 (D)
unnamed: D13.1 (K), J14.1, Q20.3 (D)
unnamed: D14.1 (K), Q17.3 (D), Q19.1 (G), R39.1
unnamed: D15.1 (K), Q18.3 (D), Q20.1 (G), R40.1
unnamed: D16.1 (K), J15.1, Q25.3 (D)
unnamed: D17.1 (K), J16.1, Q26.3 (D)
unnamed: D18.1 (K), J17.1, Q27.3 (D)
unnamed: D19.1 (K), J18.1, Q28.3 (D)
unnamed: D20.1 (K), Q21.3 (D), Q25.1 (G), R49.1
unnamed: D21.1 (K), Q22.3 (D), Q26.1 (G), R50.1
unnamed: D22.1 (K), Q23.3 (D), Q27.1 (G), R51.1
unnamed: D23.1 (K), Q24.3 (D), Q28.1 (G), R52.1
unnamed: J5.2, J6.2, J7.2, J8.2, J9.2, J10.2, J11.2, J12.2, Q11.3 (D)
unnamed: Q1.2 (B), R8.1, R53.2
unnamed: Q1.3 (C), Q29.1 (G), R3.2
unnamed: Q9.1 (G), R6.2, U1.5 (Q)
unnamed: C2.2, Q10.3 (D), R18.2, U1.7 (PRE#)
unnamed: Q10.1 (G), R20.2, R21.1
unnamed: Q11.1 (G), Q12.3 (D), R30.1
unnamed: Q12.1 (G), R26.2, R27.2
unnamed: Q14.1 (G), R28.2, R29.2
unnamed: Q15.1 (G), R32.2, R33.2
unnamed: Q17.1 (G), R35.2, R37.2
unnamed: Q18.1 (G), R36.2, R38.2
unnamed: Q21.1 (G), R41.2, R45.2
unnamed: Q22.1 (G), R42.2, R46.2
unnamed: Q23.1 (G), R43.2, R47.2
unnamed: Q24.1 (G), R44.2, R48.2
unnamed: Q29.3 (D), R1.2
unnamed: R17.1, U1.1 (CLK), U2.4
unnamed: R19.2, U1.6 (CLR#)
unnamed: U1.2 (D), U1.3 (Q#)
unnamed: R54.2, R55.1, U5.3 (~CE)
VBATT: C4.2, D24.1 (K), Q9.2 (S), R6.1, R16.2, R18.1, R19.1, U1.8 (VCC), U2.5 (VCC), U5.6 (VOUT)
VIN: C8.1, D2.2 (A), ESP32_C3_super_mini1.16 (5V), Q9.3 (D)

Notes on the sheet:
Update: 1. Switch pins for multiplexer ADC and latch disable, use ADC1 for ADC(unless ADC2 issue can be resolved) 2. Change button to 6*6 3. Switch 5V and GND for valve 4. Reduce pull down to only 1 for sensor ADC on main 5. Use multiplexer for valve MOSFET as well 6. battery NPN 2N3904S-RTK/PS rep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
Pins with multiplexer and shift register: 0: Crystal 1: Crystal 2: Multiplexer selector 1 3: Battery estimate ADC 4: Latch circuit disable 5: Multiplexer ADC 6: Sensor enable 7: Battery estimate enable 8: Multiplexer selector 2 9: Multiplexer selector 3 10: Shift register data 20: Shift register cl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

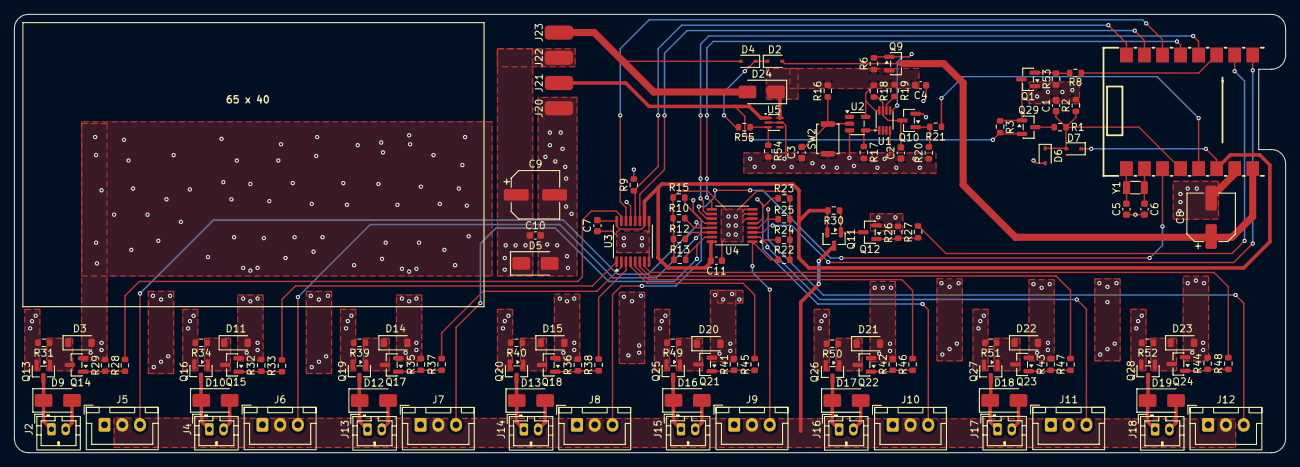
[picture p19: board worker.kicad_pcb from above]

Board: 2 copper layers, 178.9 x 61.7 mm, 133 parts (0 on the bottom side), 75 nets.

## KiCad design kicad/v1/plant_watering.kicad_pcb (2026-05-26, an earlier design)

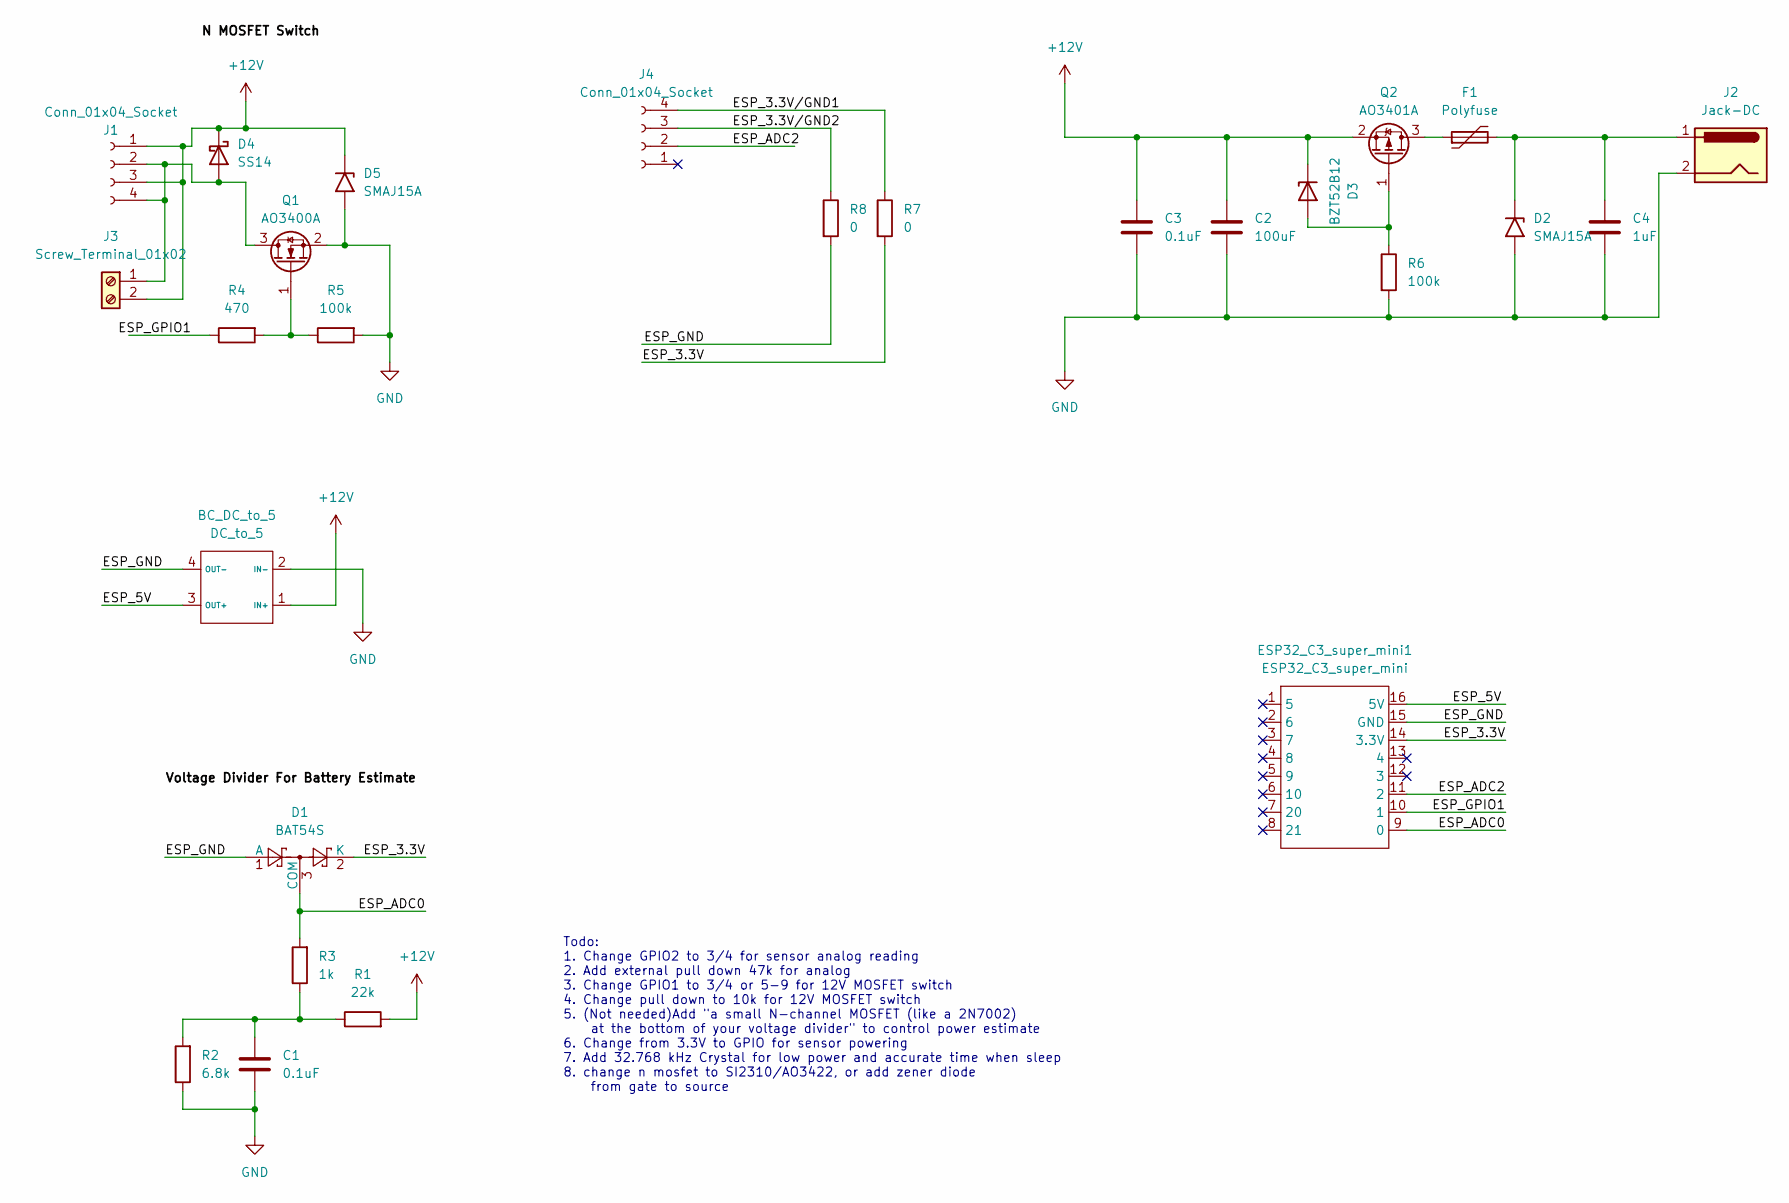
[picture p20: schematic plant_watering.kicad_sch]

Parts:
BC_DC_to_5: DC_to_5; COMM-SMD_12VTO5V
C1, C3: 0.1uF; C_0603_1608Metric
C2: 100uF; CP_Elec_6.3x5.4
C4: 1uF; C_0603_1608Metric
D1: BAT54S; SOT-23
D2, D5: SMAJ15A; D_SMA
D3: BZT52B12; D_SOD-123
D4: SS14; D_SMA
ESP32_C3_super_mini1: ESP32_C3_super_mini; 1_ESP32_C3_super_mini-SMD_16P-L22.5-W18.0-P2.54-TL
F1: Polyfuse; Fuse_1812_4532Metric
J1: Conn_01x04_Socket; CONN-SMD_2P-P1.25_XYECONN_XY-GH1.25-2A61
J2: Jack-DC; DC-IN-TH_DC-470-2.1GP
J3: Screw_Terminal_01x02; CONN-TH_WJ126V-5.0-2P
J4: Conn_01x04_Socket; CONN-TH_4P-P2.50-XH2.54-4P
Q1: AO3400A; SOT-23
Q2: AO3401A; SOT-23
R1: 22k; R_0603_1608Metric
R2: 6.8k; R_0603_1608Metric
R3: 1k; R_0603_1608Metric
R4: 470; R_0603_1608Metric
R5, R6: 100k; R_0603_1608Metric
R7, R8: 0; R_0603_1608Metric_Pad0.98x0.95mm_HandSolder

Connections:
+12V: BC_DC_to_5.1 (IN+), C2.1, C3.1, D3.1 (K), D4.1 (K), D5.1 (A1), J1.1, J1.3, J3.2, Q2.2 (S), R1.2
/ESP_3.3V: D1.2 (K), ESP32_C3_super_mini1.14 (3.3V), R7.2
/ESP_3.3V/GND1: J4.4, R7.1
/ESP_3.3V/GND2: J4.3, R8.1
/ESP_5V: BC_DC_to_5.3 (OUT+), ESP32_C3_super_mini1.16 (5V)
/ESP_ADC0: D1.3 (COM), ESP32_C3_super_mini1.9 (0), R3.2
/ESP_ADC2: ESP32_C3_super_mini1.11 (2), J4.2
/ESP_GND: BC_DC_to_5.4 (OUT-), D1.1 (A), ESP32_C3_super_mini1.15 (GND), R8.2
/ESP_GPIO1: ESP32_C3_super_mini1.10 (1), R4.1
GND: BC_DC_to_5.2 (IN-), C1.1, C2.2, C3.2, C4.2, D2.2 (A2), D5.2 (A2), J2.2, Q1.2 (S), R2.1, R5.2, R6.2
unnamed: C1.2, R1.1, R2.2, R3.1
unnamed: C4.1, D2.1 (A1), F1.2, J2.1
unnamed: D3.2 (A), Q2.1 (G), R6.1
unnamed: D4.2 (A), J1.2, J1.4, J3.1, Q1.3 (D)
unnamed: Q1.1 (G), R4.2, R5.1
unnamed: F1.1, Q2.3 (D)

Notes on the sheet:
Todo: 1. Change GPIO2 to 3/4 for sensor analog reading 2. Add external pull down 47k for analog 3. Change GPIO1 to 3/4 or 5-9 for 12V MOSFET switch 4. Change pull down to 10k for 12V MOSFET switch 5. (Not needed)Add "a small N-channel MOSFET (like a 2N7002) at the bottom of your voltage divider" to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

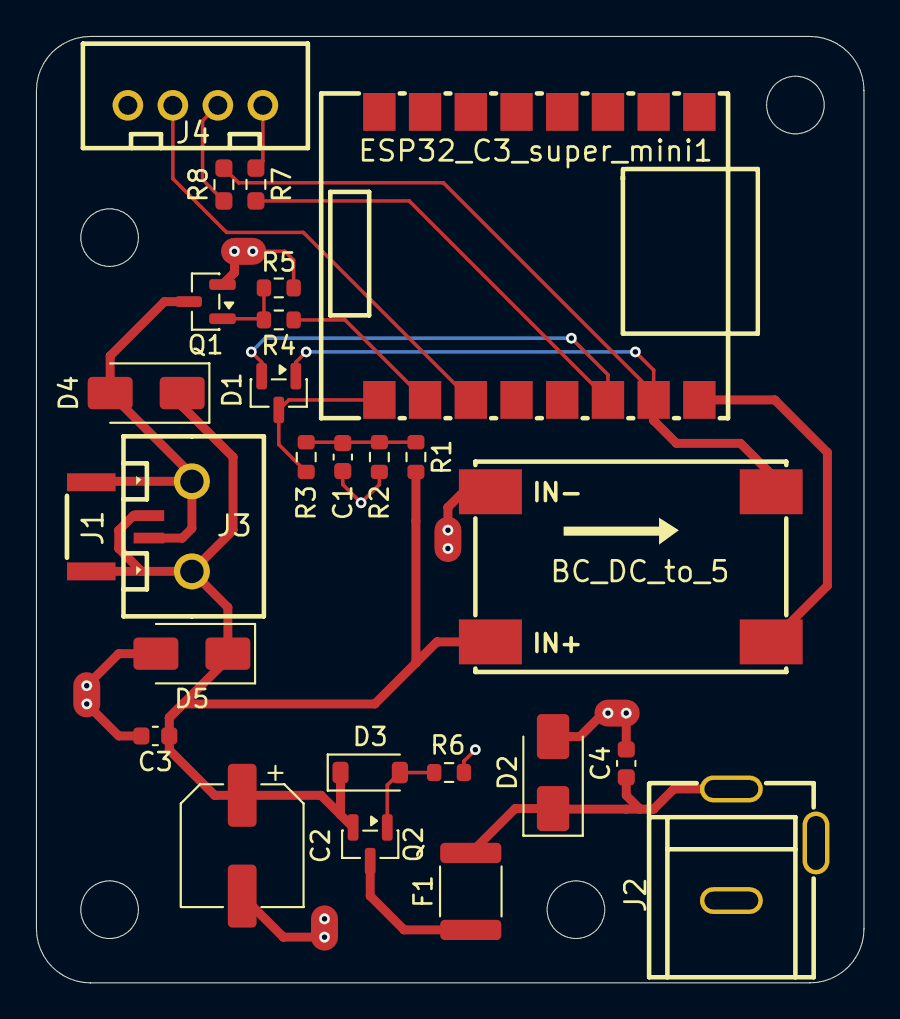
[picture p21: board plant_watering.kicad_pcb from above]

Board: 2 copper layers, 46.0 x 52.6 mm, 26 parts (0 on the bottom side), 16 nets.

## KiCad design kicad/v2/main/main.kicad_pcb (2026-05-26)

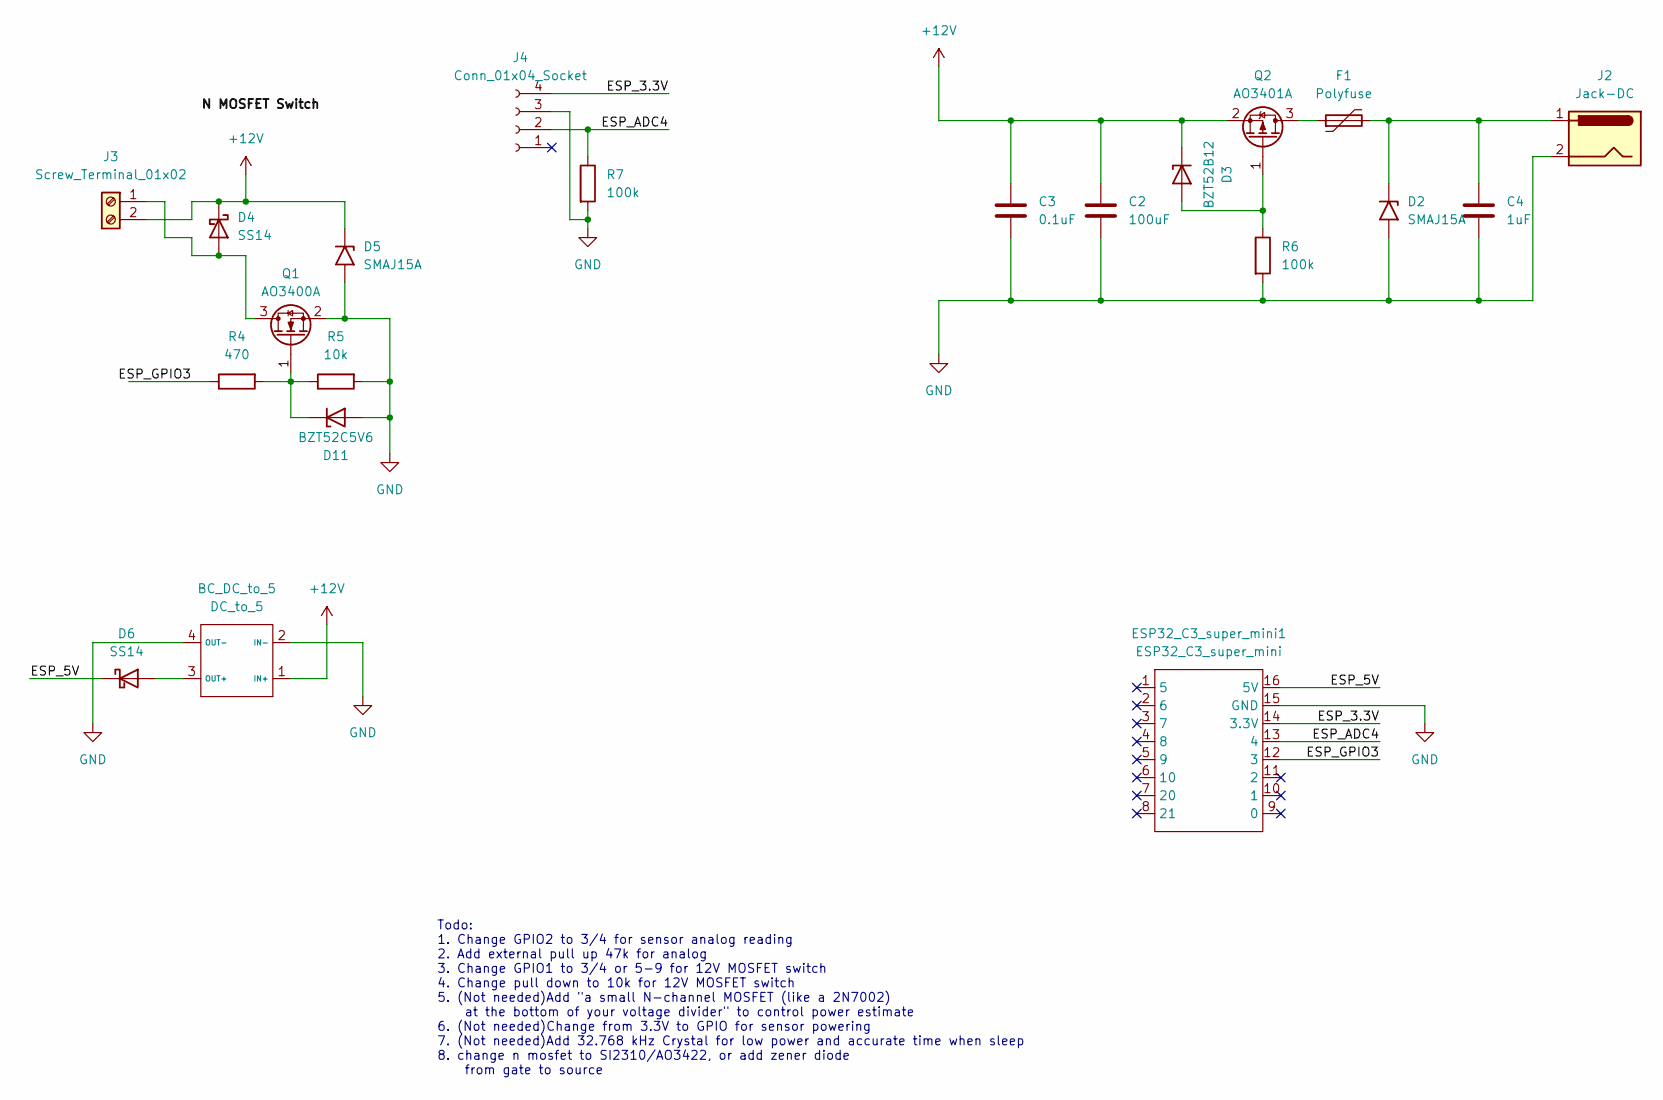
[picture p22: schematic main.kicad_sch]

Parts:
BC_DC_to_5: DC_to_5; COMM-SMD_12VTO5V
C2: 100uF; CP_Elec_6.3x5.4
C3: 0.1uF; C_0603_1608Metric
C4: 1uF; C_0603_1608Metric
D2, D5: SMAJ15A; D_SMA
D3: BZT52B12; D_SOD-123
D4, D6: SS14; D_SMA
D11: BZT52C5V6; D_SOD-123
ESP32_C3_super_mini1: ESP32_C3_super_mini; 1_ESP32_C3_super_mini-SMD_16P-L22.5-W18.0-P2.54-TL
F1: Polyfuse; Fuse_1812_4532Metric
J2: Jack-DC; DC-IN-TH_DC-470-2.1GP
J3: Screw_Terminal_01x02; CONN-TH_WJ126V-5.0-2P
J4: Conn_01x04_Socket; CONN-TH_4P-P2.50-XH2.54-4P
Q1: AO3400A; SOT-23
Q2: AO3401A; SOT-23
R4: 470; R_0603_1608Metric
R5: 10k; R_0603_1608Metric
R6, R7: 100k; R_0603_1608Metric

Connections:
+12V: BC_DC_to_5.1 (IN+), C2.1, C3.1, D3.1 (K), D4.1 (K), D5.1 (A1), J3.2, Q2.2 (S)
/ESP_3.3V: ESP32_C3_super_mini1.14 (3.3V), J4.4
/ESP_5V: D6.1 (K), ESP32_C3_super_mini1.16 (5V)
/ESP_ADC4: ESP32_C3_super_mini1.13 (4), J4.2, R7.1
/ESP_GPIO3: ESP32_C3_super_mini1.12 (3), R4.1
GND: BC_DC_to_5.2 (IN-), BC_DC_to_5.4 (OUT-), C2.2, C3.2, C4.2, D2.2 (A2), D5.2 (A2), D11.2 (A), ESP32_C3_super_mini1.15 (GND), J2.2, J4.3, Q1.2 (S), R5.2, R6.2, R7.2
unnamed: BC_DC_to_5.3 (OUT+), D6.2 (A)
unnamed: C4.1, D2.1 (A1), F1.2, J2.1
unnamed: D3.2 (A), Q2.1 (G), R6.1
unnamed: D4.2 (A), J3.1, Q1.3 (D)
unnamed: D11.1 (K), Q1.1 (G), R4.2, R5.1
unnamed: F1.1, Q2.3 (D)

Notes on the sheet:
Todo: 1. Change GPIO2 to 3/4 for sensor analog reading 2. Add external pull up 47k for analog 3. Change GPIO1 to 3/4 or 5-9 for 12V MOSFET switch 4. Change pull down to 10k for 12V MOSFET switch 5. (Not needed)Add "a small N-channel MOSFET (like a 2N7002) at the bottom of your voltage divider" to c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

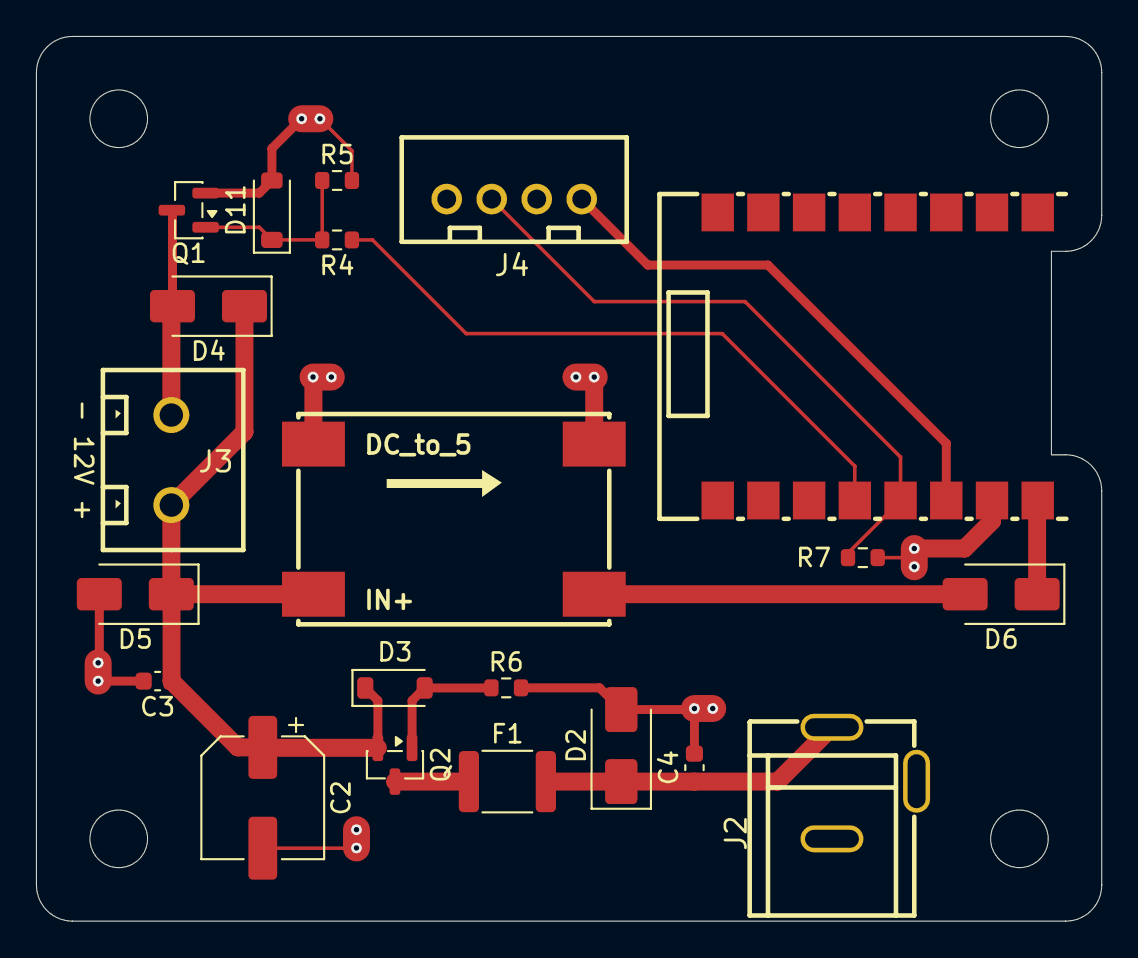
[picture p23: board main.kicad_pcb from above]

Board: 2 copper layers, 59.2 x 49.1 mm, 21 parts (0 on the bottom side), 12 nets.

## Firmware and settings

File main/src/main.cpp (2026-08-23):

#include <Arduino.h>
#include <WiFi.h>
#include <ESPmDNS.h>
#include <WiFiProvisioner.h>

#include "config.h"
#include "Pump.h"
#include "Sensor.h"
#include "WebUI.h"
#include "BluetoothMain.h"
#include "Utility.h"
#include "ClockManager.h"
#include "WateringManager.h"
#include "OtaManager.h"
#include "WorkerOtaManager.h"
#include "AutoRecovery.h"
#include "AutoWateringPolicy.h"
#include "StatusLed.h"
#include "esp_timer.h"

namespace {
constexpr int64_t MANUAL_SYNC_INTERVAL_US = 30000000LL;
constexpr uint32_t STATUS_WAIT_MS = 3000;
constexpr uint32_t AUTO_WAKE_PADDING_MS = 10000;

String gMdnsName;
bool gMdnsStarted = false;

void startMdnsIfNeeded() {
  if (gMdnsStarted || gMdnsName.isEmpty()) return;
  if (!MDNS.begin(gMdnsName.c_str())) {
    LOG("Error starting mDNS");
    return;
  }
  gMdnsStarted = true;
  LOG("mDNS started: %s.local", gMdnsName.c_str());
}

struct AutoWaterRequest {
  uint8_t mac[6];
  uint16_t potMask;
  uint16_t durations[MAX_POTS_PER_DEVICE];
  uint8_t durationCount;
};

const char* btSendStatusName(BtSendStatus status) {
  switch (status) {
    case BtSendStatus::INVALID: return "INVALID";
    case BtSendStatus::QUEUE_FULL: return "QUEUE_FULL";
    case BtSendStatus::TRANSMIT_FAILED: return "TRANSMIT_FAILED";
    case BtSendStatus::SENT: return "SENT";
    case BtSendStatus::ACKED: return "ACKED";
    default: return "UNKNOWN";
  }
}

bool synchronizeWorker(const WorkerConfig& worker, int64_t cycleStartUs) {
  if (workerOtaIsActive()) return false;
  char workerMac[13];
  macToHexLower(worker.mac, workerMac);
  WorkerNode before{};
  uint32_t generation = 0;
  if (btMainGetNodeByMac(worker.mac, before)) generation = before.statusGeneration;
  LOG("WaterTask sync probe start worker=%s previous_generation=%lu",
      workerMac, static_cast<unsigned long>(generation));

  BT_TLV::BtBodyBuilder probe;
  BT_TLV::btBodyBegin(probe, BT_TLV::TYPE_CMD_PROBE);
  BtSendResult sent =
      btMainSendCommand(worker.mac, probe.data, probe.len, 2, 700);
  char ack[13];
  macToHexLower(sent.ackMac, ack);
  LOG("WaterTask sync probe result worker=%s status=%s started=%u ack=%s id=%08lx%08lx:%lu",
      workerMac, btSendStatusName(sent.status), sent.transmissionStarted ? 1u : 0u,
      ack, static_cast<unsigned long>(sent.messageId.sessionId >> 32),
      static_cast<unsigned long>(sent.messageId.sessionId & 0xFFFFFFFFULL),
      static_cast<unsigned long>(sent.messageId.sequence));
  if (!sent.transmissionStarted) return false;

  WorkerNode refreshed{};
  bool gotStatus = btMainWaitForStatus(worker.mac, generation,
                                       STATUS_WAIT_MS, refreshed);
  bool fresh = gotStatus && refreshed.lastSyncUs >= cycleStartUs;
  LOG("WaterTask sync status worker=%s got_status=%u fresh=%u new_generation=%lu",
      workerMac, gotStatus ? 1u : 0u, fresh ? 1u : 0u,
      static_cast<unsigned long>(gotStatus ? refreshed.statusGeneration : generation));
  return fresh;
}

int synchronizeConfiguredWorkers(int64_t cycleStartUs) {
  int refreshed = 0;
  int count = getWorkerConfigCount();
  LOG("WaterTask sync cycle start workers=%d", count);
  for (int i = 0; i < count; ++i) {
    WorkerConfig worker{};
    if (getWorkerConfigAt(i, worker) &&
        synchronizeWorker(worker, cycleStartUs)) {
      ++refreshed;
    }
  }
  LOG("WaterTask sync cycle end refreshed=%d/%d", refreshed, count);
  return refreshed;
}

bool wateringWindowOpen(const Settings& settings) {
  uint32_t secondOfDay = clockGetCurrentTimeOfDaySec();
  if (settings.activeStart <= settings.activeEnd) {
    return secondOfDay >= settings.activeStart &&
           secondOfDay <= settings.activeEnd;
  }
  return secondOfDay >= settings.activeStart ||
         secondOfDay <= settings.activeEnd;
}

void waterFreshWorkers(int64_t cycleStartUs, uint32_t nowUtc) {
  int count = getWorkerConfigCount();
  LOG("WaterTask watering fresh workers start count=%d", count);
  AutoWaterRequest requests[MAX_WORKER_COUNT] = {};
  int requestCount = 0;
  for (int i = 0; i < count; ++i) {
    WorkerConfig worker{};
    WorkerNode node{};
    if (!getWorkerConfigAt(i, worker) ||
        !btMainGetNodeByMac(worker.mac, node) ||
        node.lastSyncUs < cycleStartUs) {
      if (getWorkerConfigAt(i, worker)) {
        char workerMac[13];
        macToHexLower(worker.mac, workerMac);
        LOG("WaterTask watering skip worker=%s reason=not_fresh", workerMac);
      }
      continue;
    }

    char workerMac[13];
    macToHexLower(worker.mac, workerMac);
    int potCount = min(static_cast<int>(worker.potCount),
                       static_cast<int>(node.potCount));
    AutoWaterRequest request{};
    memcpy(request.mac, worker.mac, sizeof(request.mac));
    for (int pot = 0; pot < potCount; ++pot) {
      uint16_t correctedSoil =
          getCorrectedSoilMoisture(node.batteryMv, node.soils[pot]);
      if (autoWateringPotEligible(
              nowUtc, worker.lastAutoWateringUtcSec[pot],
              worker.waterIntervals[pot], node.soils[pot], correctedSoil,
              worker.thresholds[pot])) {
        request.potMask |= static_cast<uint16_t>(1u << pot);
        request.durations[request.durationCount++] = worker.durations[pot];
      }
    }
    LOG("WaterTask watering decision worker=%s pot_count=%d mask=0x%04x duration_count=%u",
        workerMac, potCount, static_cast<unsigned>(request.potMask),
        static_cast<unsigned>(request.durationCount));
    if (request.potMask != 0 && requestCount < MAX_WORKER_COUNT) {
      requests[requestCount++] = request;
    }
  }

  if (requestCount == 0) {
    LOG("WaterTask watering fresh workers end reason=no_candidates");
    return;
  }
  if (isTankLow()) {
    LOG("WaterTask watering batch rejected reason=tank_low tank_mv=%u",
        static_cast<unsigned>(getTankLevel()));
    return;
  }

  Settings settings{};
  getSettingsSnapshot(settings);
  LOG("WaterTask watering pump start candidates=%d prime_seconds=%u",
      requestCount, static_cast<unsigned>(settings.pumpDelaySeconds));
  pumpOn();

  int64_t primeDeadlineUs =
      esp_timer_get_time() +
      static_cast<int64_t>(settings.pumpDelaySeconds) * 1000000LL;
  bool tankLow = false;
  while (esp_timer_get_time() < primeDeadlineUs) {
    if (isTankLow()) {
      tankLow = true;
      break;
    }
    vTaskDelay(pdMS_TO_TICKS(100));
  }
  if (isTankLow()) tankLow = true;

  CompletedAutoWatering completions[MAX_WORKER_COUNT] = {};
  size_t completionCount = 0;
  if (!tankLow) {
    for (int i = 0; i < requestCount; ++i) {
      if (isTankLow()) {
        tankLow = true;
        LOG("WaterTask watering batch abort reason=tank_low index=%d tank_mv=%u",
            i, static_cast<unsigned>(getTankLevel()));
        break;
      }
      AutoWaterRequest& request = requests[i];
      char workerMac[13];
      macToHexLower(request.mac, workerMac);
      bool completed = wateringExecuteWorker(
          request.mac, request.potMask, request.durations,
          request.durationCount, true);
      if (completed) {
        if (completionCount < MAX_WORKER_COUNT) {
          memcpy(completions[completionCount].mac, request.mac,
                 sizeof(completions[completionCount].mac));
          completions[completionCount].potMask = request.potMask;
          ++completionCount;
        }
      }
      LOG("WaterTask watering worker=%s completed=%u",
          workerMac, completed ? 1u : 0u);
      if (isTankLow()) {
        tankLow = true;
        LOG("WaterTask watering batch abort reason=tank_low_after_worker worker=%s tank_mv=%u",
            workerMac, static_cast<unsigned>(getTankLevel()));
        break;
      }
    }
  } else {
    LOG("WaterTask watering batch abort reason=tank_low_during_priming tank_mv=%u",
        static_cast<unsigned>(getTankLevel()));
  }

  LOG("WaterTask watering pump stop");
  pumpOff();
  if (completionCount != 0) {
    uint64_t completedUtc = clockGetCurrentEpochSec();
    if (completedUtc != 0 && completedUtc <= UINT32_MAX) {
      recordCompletedAutoWateringBatch(
          completions, completionCount, static_cast<uint32_t>(completedUtc));
    }
  }
  LOG("WaterTask watering fresh workers end completed=%u tank_low=%u",
      completionCount != 0 ? 1u : 0u, tankLow ? 1u : 0u);
}

void sendWorkerToSleepAt(const uint8_t mac[6], int64_t wakeAtUs) {
  int64_t remainingUs = wakeAtUs - esp_timer_get_time();
  uint32_t seconds = remainingUs > 0
                         ? static_cast<uint32_t>((remainingUs + 999999) / 1000000)
                         : 60;
  seconds = max(seconds, static_cast<uint32_t>(60));
  BT_TLV::BtBodyBuilder sleep;
  BT_TLV::btBodyBegin(sleep, BT_TLV::TYPE_CMD_SLEEP);
  if (!BT_TLV::btTlvAppendU32(sleep, BT_TLV::FIELD_SLEEP_SEC, seconds)) return;
  char workerMac[13];
  macToHexLower(mac, workerMac);
  LOG("WaterTask sleep send worker=%s seconds=%lu wake_at_us=%lld",
      workerMac, static_cast<unsigned long>(seconds),
      static_cast<long long>(wakeAtUs));
  BtSendResult result = btMainSendCommand(mac, sleep.data, sleep.len, 2, 700);
  LOG("WaterTask sleep result worker=%s status=%s started=%u id=%08lx%08lx:%lu",
      workerMac, btSendStatusName(result.status),
      result.transmissionStarted ? 1u : 0u,
      static_cast<unsigned long>(result.messageId.sessionId >> 32),
      static_cast<unsigned long>(result.messageId.sessionId & 0xFFFFFFFFULL),
      static_cast<unsigned long>(result.messageId.sequence));
}

void sendWorkersToSleepAt(int64_t wakeAtUs) {
  int count = getWorkerConfigCount();
  LOG("WaterTask sleep cycle start workers=%d wake_at_us=%lld",
      count, static_cast<long long>(wakeAtUs));
  for (int i = 0; i < count; ++i) {
    WorkerConfig worker{};
    if (getWorkerConfigAt(i, worker)) sendWorkerToSleepAt(worker.mac, wakeAtUs);
  }
  LOG("WaterTask sleep cycle end");
}

void handleWorkerSleepRequests(int64_t wakeAtUs) {
  uint8_t mac[6];
  while (btMainTakeSleepRequest(mac)) {
    char workerMac[13];
    macToHexLower(mac, workerMac);
    LOG("WaterTask sleep request handle worker=%s", workerMac);
    sendWorkerToSleepAt(mac, wakeAtUs);
  }
}
}

void TaskWeb(void*) {
  for (;;) {
    webHandleClientLoop();
    vTaskDelay(pdMS_TO_TICKS(10));
  }
}

void TaskSensor(void*) {
  for (;;) {
    readTankLevel();
    vTaskDelay(pdMS_TO_TICKS(1000));
  }
}

void TaskWatering(void*) {
  int64_t lastSyncUs = 0;
  int64_t lastAutoWaitLogUs = 0;
  bool previousAuto = false;
  bool loggedManualMode = false;

  for (;;) {
    if (otaIsActive() || workerOtaIsActive()) {
      setRuntimeState(UPDATING);
      vTaskDelay(pdMS_TO_TICKS(250));
      continue;
    }
    bool automatic = getAutoEnabled();
    if (!automatic) {
      if (!loggedManualMode || previousAuto) {
        LOG("WaterTask mode=manual");
        loggedManualMode = true;
      }
      previousAuto = false;
      setRuntimeState(READY);
      setDataSyncRuntime(0, 0);
      if (wateringProcessOneManual()) continue;
      int64_t nowUs = esp_timer_get_time();
      if (lastSyncUs == 0 || nowUs - lastSyncUs >= MANUAL_SYNC_INTERVAL_US) {
        if (otaIsActive() || workerOtaIsActive()) continue;
        LOG("WaterTask manual sync due now_us=%lld last_sync_us=%lld",
            static_cast<long long>(nowUs), static_cast<long long>(lastSyncUs));
        setRuntimeState(SYNCING);
        synchronizeConfiguredWorkers(nowUs);
        lastSyncUs = esp_timer_get_time();
        setRuntimeState(READY);
        LOG("WaterTask manual sync complete last_sync_us=%lld",
            static_cast<long long>(lastSyncUs));
      }
      vTaskDelay(pdMS_TO_TICKS(100));
      continue;
    }

    if (!previousAuto) {
      LOG("WaterTask mode=auto");
      lastSyncUs = 0;
      setDataSyncRuntime(0, 0);
      previousAuto = true;
      loggedManualMode = false;
    }

    Settings settings{};
    getSettingsSnapshot(settings);
    int64_t nowUs = esp_timer_get_time();
    int64_t syncIntervalUs =
        static_cast<int64_t>(settings.dataSyncInterval) * 1000000LL;
    if (lastSyncUs != 0 && nowUs - lastSyncUs < syncIntervalUs) {
      if (lastAutoWaitLogUs == 0 || nowUs - lastAutoWaitLogUs >= MANUAL_SYNC_INTERVAL_US) {
        LOG("WaterTask auto sleep-window remaining_us=%lld",
            static_cast<long long>(syncIntervalUs - (nowUs - lastSyncUs)));
        lastAutoWaitLogUs = nowUs;
      }
      handleWorkerSleepRequests(lastSyncUs + syncIntervalUs);
      setDataSyncRuntime(lastSyncUs, lastSyncUs + syncIntervalUs);
      vTaskDelay(pdMS_TO_TICKS(250));
      continue;
    }
    lastAutoWaitLogUs = 0;

    if (otaIsActive() || workerOtaIsActive()) continue;
    setRuntimeState(SYNCING);
    LOG("WaterTask auto sync wake padding_ms=%lu",
        static_cast<unsigned long>(AUTO_WAKE_PADDING_MS));
    vTaskDelay(pdMS_TO_TICKS(AUTO_WAKE_PADDING_MS));
    if (otaIsActive() || workerOtaIsActive()) continue;
    int64_t cycleStartUs = esp_timer_get_time();
    synchronizeConfiguredWorkers(cycleStartUs);
    lastSyncUs = esp_timer_get_time();
    int64_t completedSyncUs = lastSyncUs;

    uint64_t nowUtc = clockGetCurrentEpochSec();
    bool clockOk = clockIsValid() && nowUtc != 0;
    bool windowOpen = clockOk && wateringWindowOpen(settings);
    LOG("WaterTask auto watering gate utc=%lu window_open=%u",
        static_cast<unsigned long>(nowUtc), windowOpen ? 1u : 0u);
    if (clockOk && windowOpen && nowUtc <= UINT32_MAX) {
      if (otaIsActive() || workerOtaIsActive()) continue;
      setRuntimeState(WATERING);
      waterFreshWorkers(cycleStartUs, static_cast<uint32_t>(nowUtc));
    } else {
      LOG("WaterTask auto watering skipped");
    }

    setRuntimeState(SLEEPING);
    lastSyncUs = esp_timer_get_time();
    int64_t wakeAtUs =
        lastSyncUs + static_cast<int64_t>(settings.dataSyncInterval) * 1000000LL;
    setDataSyncRuntime(completedSyncUs, wakeAtUs);
    sendWorkersToSleepAt(wakeAtUs);
    vTaskDelay(pdMS_TO_TICKS(250));
  }
}

void setup() {
  Serial.begin(115200);
  bool resumeAutoAfterCrash = autoRecoveryInitialize();
  otaManagerInit();
  workerOtaManagerInit();
  WiFi.setTxPower(WIFI_POWER_8_5dBm);
  statusLedBegin();
  vTaskDelay(pdMS_TO_TICKS(3000));
  char btmac[13];
  getBtMacHex(btmac);
  LOG("Bluetooth MAC address: %s", btmac);

  char wifiLast6[7];
  getWifiMacLast6Hex(wifiLast6);
  gMdnsName = String("plant-watering-") + wifiLast6;

  loadSettings();
  clockManagerInit();

  WiFiProvisioner provisioner;
  WiFiProvisioner::Config &config = provisioner.getConfig();
  config.PROJECT_TITLE = "Plant Watering";
  config.AP_NAME = gMdnsName.c_str();
  provisioner.onSuccess([](const char* ssid, const char* password, const char*) {
    saveWifiCred(ssid, password);
  });
  provisioner.getConfig().SHOW_INPUT_FIELD = false;
  provisioner.getConfig().SHOW_RESET_FIELD = false;

  WiFiStartupResult wifiResult = connectToWiFi();
  bool bootOfflineForRecovery =
      resumeAutoAfterCrash &&
      wifiResult == WiFiStartupResult::CONNECTION_FAILED;
  if (wifiResult != WiFiStartupResult::CONNECTED &&
      !bootOfflineForRecovery) {
    provisioner.startProvisioning();
    while (WiFi.status() != WL_CONNECTED) delay(500);
  } else if (bootOfflineForRecovery) {
    LOG("Crash recovery continuing offline; WiFi will retry in background");
  }
  initializeWiFiMaintenance();
  clockRequestNtpSync();

  pumpBegin();
  sensorBegin();
  wateringManagerInit();
  btMainBegin();
  startMdnsIfNeeded();

  webBegin();
  TaskHandle_t webTask = nullptr;
  TaskHandle_t sensorTask = nullptr;
  TaskHandle_t wateringTask = nullptr;
  xTaskCreate(TaskSensor, "sensorTask", 2048, nullptr, 2, &sensorTask);
  xTaskCreate(TaskWatering, "waterTask", 8192, nullptr, 2, &wateringTask);
  if (!otaMarkRunningAppValid()) {
    LOG("OTA running app validation did not complete");
  }
  xTaskCreate(TaskWeb, "webTask", 6144, nullptr, 1, &webTask);
  webSetDiagnosticsTaskHandles(xTaskGetCurrentTaskHandle(), webTask,
                               sensorTask, wateringTask);
  if (resumeAutoAfterCrash) {
    LOG("Restoring auto mode after eligible crash/watchdog reset");
    setAutoEnabled(true);
  }
}

void loop() {
  bool wifiReconnected = serviceWiFiMaintenance();
  if (wifiReconnected && !gMdnsStarted) startMdnsIfNeeded();
  clockManagerLoop();
  otaManagerLoop();
  workerOtaManagerLoop();
  maybeSaveSettings();
  vTaskDelay(pdMS_TO_TICKS(1000));
}

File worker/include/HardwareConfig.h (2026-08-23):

#pragma once
#include <Arduino.h>

// Hardware target selection
// Define exactly one of the HW_TARGET_* macros via build flags.
// Examples: -D HW_V1_1POT_REV_A, -D HW_V2_8POT_REV_A, -D HW_TARGET_8P_REV_B

#if defined(HW_V1_1POT_REV_A)

#define WORKER_POT_COUNT 1
#define SOIL_PIN 3
#define VALVE_PIN 1
#define BATT_PIN 4

#define WORKER_REQUIRES_EXT_RTC_XTAL 0

#elif defined(HW_V2_8POT_REV_A)

#define WORKER_POT_COUNT 8

#define SOIL_EN_PIN 6
#define MUX_ADC_PIN 5
#define MUX_SEL_PIN0 2
#define MUX_SEL_PIN1 8
#define MUX_SEL_PIN2 9

#define WORKER_REQUIRES_EXT_RTC_XTAL 1
#define WORKER_BOOT_LED_PIN 8
#define WORKER_BOOT_LED_ACTIVE_LOW 1

#define SHIFT_DATA_PIN 10
#define SHIFT_CLOCK_PIN 20
#define SHIFT_LATCH_PIN 21

#define BATT_EN_PIN 7
#define BATT_ADC_PIN 3

#define SHUTDOWN_PIN 4

#elif defined(HW_V2_8POT_REV_B)

#define WORKER_POT_COUNT 8

#define SOIL_EN_PIN 6
#define MUX_ADC_PIN 4
#define MUX_SEL_PIN0 2
#define MUX_SEL_PIN1 8
#define MUX_SEL_PIN2 9

#define WORKER_REQUIRES_EXT_RTC_XTAL 1
#define WORKER_BOOT_LED_PIN 8
#define WORKER_BOOT_LED_ACTIVE_LOW 1

#define SHIFT_DATA_PIN 10
#define SHIFT_CLOCK_PIN 20
#define SHIFT_LATCH_PIN 21

#define BATT_EN_PIN 7
#define BATT_ADC_PIN 3

#define SHUTDOWN_PIN 5

#elif defined(HW_TARGET_16POT_REV_A)

#define WORKER_POT_COUNT 16
#define MUX_ADC_PIN 3
#define MUX_SEL_PIN0 5
#define MUX_SEL_PIN1 6
#define MUX_SEL_PIN2 7
#define SHIFT_DATA_PIN 9
#define SHIFT_CLOCK_PIN 10
#define SHIFT_LATCH_PIN 11
#define BATT_PIN 4

#define WORKER_REQUIRES_EXT_RTC_XTAL 0

#else
#error "Please define one HW_TARGET_* build flag (e.g. HW_V1_1POT_REV_A)"
#endif

// Derived constants
#define SHIFT_REG_CHIPS ((WORKER_POT_COUNT + 7) / 8)

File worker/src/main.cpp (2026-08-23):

#include <Arduino.h>
#include "nvs_flash.h"
#include "BluetoothWorker.h"
#include "Sensor.h"
#include "Valve.h"
#include "Battery.h"
#include "WorkerOtaService.h"
#include "WorkerBootClock.h"

// Default periodic status interval (seconds) while not connected to main
static const uint32_t STATUS_INTERVAL = 10;
static const uint32_t SENSOR_INTERVAL = 5;

void TaskSensors(void *pvParameters) {
	(void) pvParameters;
	for (;;) {
		readWorkerSensors();
		vTaskDelay(pdMS_TO_TICKS(SENSOR_INTERVAL * 1000));
	}
}

void setup() {
	Serial.begin(115200);
	// analogSetAttenuation(ADC_11db);
    valveBegin();
	vTaskDelay(pdMS_TO_TICKS(3000));
	char btmac[13]; getBtMacHex(btmac);
	LOG("Bluetooth MAC address: %s", btmac);
	
  	esp_log_level_set("gpio", ESP_LOG_WARN);
  	esp_log_level_set("NimBLE", ESP_LOG_WARN);
	
    battBegin();
    sensorBegin();
    readWorkerSensors();

	btWorkerBegin();
    
	xTaskCreate(TaskSensors, "sensorTask", 3072, NULL, 2, NULL);
}

void loop() {
    workerOtaServiceLoop();
    if (workerOtaIsActive()) {
        vTaskDelay(pdMS_TO_TICKS(100));
        return;
    }
    vTaskDelay(pdMS_TO_TICKS(STATUS_INTERVAL * 1000));
    workerOtaServiceLoop();
	// No communication from main over certain time, assuming lost connection, reset main mac and start broadcast again
	if (btLastCommOverdue()) mainMacReset();
	if (!mainMacIsSet()) {
		// read sensor and advertise periodically
		btWorkerAdvertiseStatus();
	}
}

// If you are using C++ (which you are for NimBLE), 
// app_main must be declared with extern "C"
extern "C" void app_main() {
	workerBootRtcClockGate();

	esp_err_t ret = nvs_flash_init();
    if (ret == ESP_ERR_NVS_NO_FREE_PAGES || ret == ESP_ERR_NVS_NEW_VERSION_FOUND) {
        ESP_ERROR_CHECK(nvs_flash_erase());
        ret = nvs_flash_init();
    }
    ESP_ERROR_CHECK(ret);

    // 1. Initialize the Arduino stack
    initArduino();

    // 2. Call your setup function
    setup();

    // 3. In ESP-IDF, you usually create a task for the loop 
    // or just run a while(1) here.
    while (true) {
        loop();
        // Crucial: vTaskDelay prevents the Watchdog Timer from 
        // screaming because the loop is hogging the CPU.
        vTaskDelay(1 / portTICK_PERIOD_MS); 
    }
}

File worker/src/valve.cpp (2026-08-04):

#include "Valve.h"
#include "Utility.h"
#include <Arduino.h>
#include "HardwareConfig.h"
#include "esp_timer.h"
#include "freertos/semphr.h"

static volatile uint16_t gValveState = 0;
static int64_t gBatteryBlockedUntilUs = 0;
static SemaphoreHandle_t gValveBatteryMutex = nullptr;
static constexpr int64_t BATTERY_RECOVERY_US = 5000000LL;

static void ensureValveBatteryMutex() {
  if (!gValveBatteryMutex) gValveBatteryMutex = xSemaphoreCreateMutex();
}

static uint16_t setValveState(uint16_t nextState) {
  ensureValveBatteryMutex();
  int64_t nowUs = esp_timer_get_time();
  xSemaphoreTake(gValveBatteryMutex, portMAX_DELAY);
  uint16_t previousState = gValveState;
  gValveState = nextState;
  if (previousState != 0 && nextState == 0) {
    gBatteryBlockedUntilUs = nowUs + BATTERY_RECOVERY_US;
  }
  xSemaphoreGive(gValveBatteryMutex);
  return nextState;
}

static uint16_t updateValveBit(uint8_t idx, bool enabled) {
  ensureValveBatteryMutex();
  int64_t nowUs = esp_timer_get_time();
  xSemaphoreTake(gValveBatteryMutex, portMAX_DELAY);
  uint16_t previousState = gValveState;
  uint16_t nextState = enabled
                           ? static_cast<uint16_t>(previousState | (1u << idx))
                           : static_cast<uint16_t>(previousState & ~(1u << idx));
  gValveState = nextState;
  if (previousState != 0 && nextState == 0) {
    gBatteryBlockedUntilUs = nowUs + BATTERY_RECOVERY_US;
  }
  xSemaphoreGive(gValveBatteryMutex);
  return nextState;
}

static void resetValveState() {
  ensureValveBatteryMutex();
  xSemaphoreTake(gValveBatteryMutex, portMAX_DELAY);
  gValveState = 0;
  gBatteryBlockedUntilUs = 0;
  xSemaphoreGive(gValveBatteryMutex);
}

bool valveBeginBatterySampling() {
  ensureValveBatteryMutex();
  int64_t nowUs = esp_timer_get_time();
  xSemaphoreTake(gValveBatteryMutex, portMAX_DELAY);
  bool allowed = gValveState == 0 && nowUs >= gBatteryBlockedUntilUs;
  if (!allowed) xSemaphoreGive(gValveBatteryMutex);
  return allowed;
}

void valveEndBatterySampling() {
  if (gValveBatteryMutex) xSemaphoreGive(gValveBatteryMutex);
}

#if WORKER_POT_COUNT == 1

void valveBegin() {
  pinMode(VALVE_PIN, OUTPUT);
  digitalWrite(VALVE_PIN, LOW);
  resetValveState();
}

void valveOn(uint8_t idx) {
  (void)idx;
  LOG("Valve on");
  setValveState(1);
  digitalWrite(VALVE_PIN, HIGH);
}

void valveOff(uint8_t idx) {
  (void)idx;
  LOG("Valve off");
  setValveState(0);
  digitalWrite(VALVE_PIN, LOW);
}

void valveSetMask(uint16_t mask) {
  if (mask & 0x1) valveOn(0); else valveOff(0);
}

#else

static const uint16_t VALVE_MASK_ALL = (WORKER_POT_COUNT >= 16) ? 0xFFFF : ((1u << WORKER_POT_COUNT) - 1);

static void writeShiftRegisters(uint16_t mask) {
  uint16_t m = mask & VALVE_MASK_ALL;
  digitalWrite(SHIFT_LATCH_PIN, LOW);
  // send bytes MSB-first so chip ordering is consistent
  for (int chip = SHIFT_REG_CHIPS - 1; chip >= 0; --chip) {
    uint8_t b = (m >> (chip * 8)) & 0xFF;
    shiftOut(SHIFT_DATA_PIN, SHIFT_CLOCK_PIN, MSBFIRST, b);
  }
  digitalWrite(SHIFT_LATCH_PIN, HIGH);
  vTaskDelay(pdMS_TO_TICKS(1));
  digitalWrite(SHIFT_LATCH_PIN, LOW);
}

void valveBegin() {
  pinMode(SHIFT_DATA_PIN, OUTPUT);
  pinMode(SHIFT_CLOCK_PIN, OUTPUT);
  pinMode(SHIFT_LATCH_PIN, OUTPUT);
  digitalWrite(SHIFT_LATCH_PIN, LOW);
  resetValveState();
  writeShiftRegisters(0);
}

void valveOn(uint8_t idx) {
  if (idx >= WORKER_POT_COUNT) return;
  writeShiftRegisters(updateValveBit(idx, true));
}

void valveOff(uint8_t idx) {
  if (idx >= WORKER_POT_COUNT) return;
  writeShiftRegisters(updateValveBit(idx, false));
}

void valveSetMask(uint16_t mask) {
  writeShiftRegisters(setValveState(mask & VALVE_MASK_ALL));
}

#endif

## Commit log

2026-05-26 add kicad and readme
    [main.kicad_pcb, main.kicad_sch, plant_watering.kicad_pcb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]
2026-05-28 update worker battery estimate logic
2026-08-04 V2, mass updates, OTA, clock, web page, and many
    [partitions.csv]
